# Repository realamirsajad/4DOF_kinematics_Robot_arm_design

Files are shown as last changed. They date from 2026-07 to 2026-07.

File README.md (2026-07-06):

# 4DOF_Robot Kinematics and Dynamics
4DOF arm robot for robotic and kinematics and how to design it by inventor designer cad and make a PD controller for that by Adams



The complete guideline and report can be viewed in the Instruction PDF file.

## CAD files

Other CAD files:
finalkinematic/AssemblyfinalRRPR.iam
finalkinematic/AssemblyfinalRRPR.x_t
finalkinematic/OldVersions/AssemblyfinalRRPR.0004.iam
finalkinematic/OldVersions/Part1Grroundfinal.0001.ipt
finalkinematic/OldVersions/Part1final.0001.ipt
finalkinematic/OldVersions/Part4final.0002.ipt
finalkinematic/OldVersions/Part4final.0003.ipt
finalkinematic/Part1Grroundfinal.ipt
finalkinematic/Part1final.ipt
finalkinematic/Part2final.ipt
finalkinematic/Part3final.ipt
finalkinematic/Part4final.ipt

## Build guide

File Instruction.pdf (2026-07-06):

Robot Kinematics and Dynamics report

The designed manipulator is a 4-degree-of-freedom (4-DOF) selective compliance robot intended for pick-and-place tasks on a conveyor belt. The combination of two revolute joints (RR), one prismatic joint (P), and a final revolute joint (R) allow positioning in 3D space while maintaining orientation. The prismatic joint provides vertical lift, and the offset between links ensures a larger workspace without self-collision.
According to assignment file, first we design our RRPR robot:

### 1. CAD Design (Autodesk Inventor)

- Base (orange): Fixed to ground.
- Link 1 (brown): Revolute joint (θ₁) about vertical axis.
- Link 2 (yellow): Revolute joint (θ₂) about horizontal axis.
- Link 3 (red): Prismatic joint (d₃) with an offset (non-zero distance between joint axes).
- Link 4 (light blue): End-effector, revolute joint (θ₄) about vertical axis.
Parts:
1. Ground base
As we said we have a 600 mm * 600 mm square which is fixed to the ground and it is stable and does not move. The depth of this part is 50 mm. I designed a circle as a hole in middle of this square with 100 mm diameter for connecting part 1 to that. I also added fillets for better view.

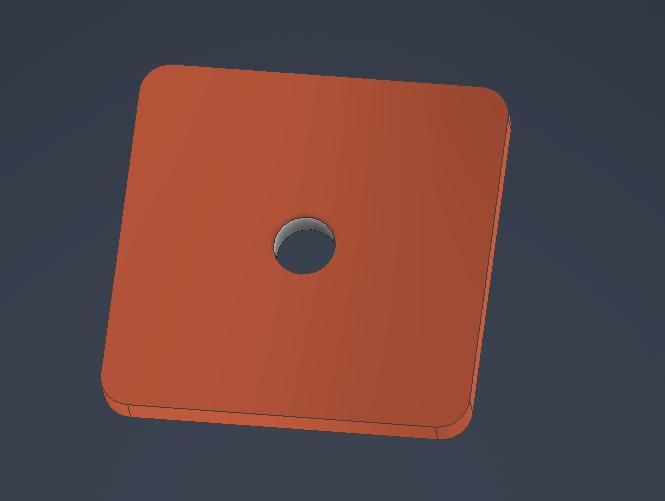
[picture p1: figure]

2. Part 1 (first revolute link)
Now we should have a cylinder attached to main part one to fit in the base part hole. So, the diameter of the hole is 100 mm again with 50 mm depth. The diameter of the base of this part is 500 mm. As it is shown in the picture below, there is a cylinder with 240 mm diameter and 750 mm height. This part 1 can rotate around itself (z axis). In the other side of this cylinder there is a empty space for moving next part freely and to circle hole with 150 mm diameter for attaching part 2. I also added fillets for better view. (l1 = 650 mm)

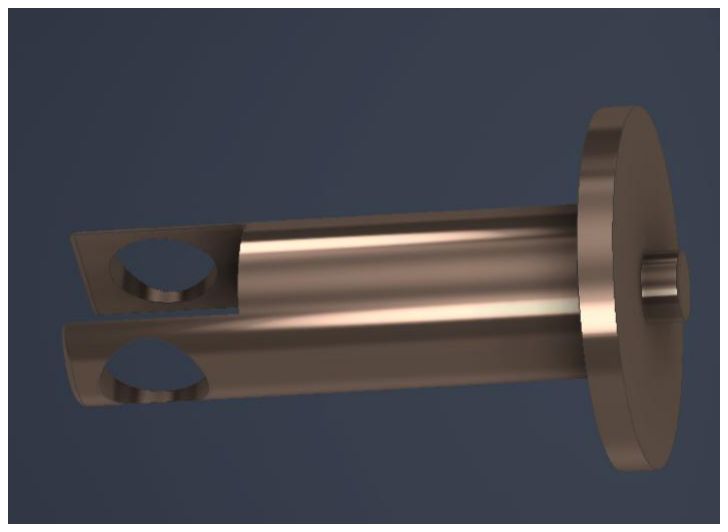
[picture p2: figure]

3. Part 2 (second revolute link)
In this part I made another horizontal cylinder for attaching to previous holes with same size (150 mm diameter again and the length of this cylinder is 240 mm). I removed a rectangular cube of this cylinder to attach the other part easier and prettier. Then I made a simple rectangular cube with 500 mm length (l2), 120 mm width, (100 mm depth). At end of this part, there is 80 mm *60 mm rectangular hole (with 2 mm fillet in each side for being more attractive), for connecting the third part. So, this part can move freely. This is another rotational part.

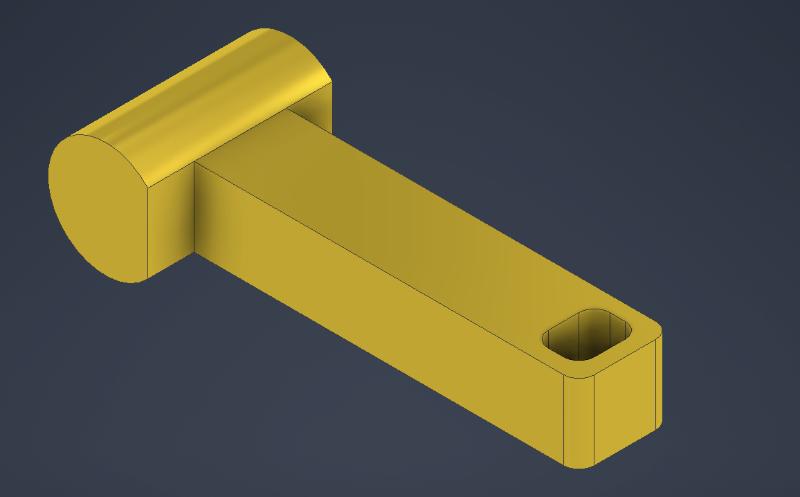
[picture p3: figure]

4. Part 3 (prismatic link)
This part is prismatic. For fitting in previous hole, the size of the rectangular cube with 500 mm length, should be 60 mm * 80 mm again. In begin of this part I designed a bigger rectangular which is 100 mm * 80 mm and 25 mm depth and the reason is this part does not pass the hole and stuck there. I also added fillets (this time around 5mm for the whole part) for better view. At other side, we have an offset (one non-zero offset between two consecutive link 4 & 5), which makes this part like a L shape, the lower part has 190 mm length (l32), and like part 1, there are 2 holes with 40 mm diameter. There are a few 2 mm fillets for better view in the last part which is not affecting the robot application.

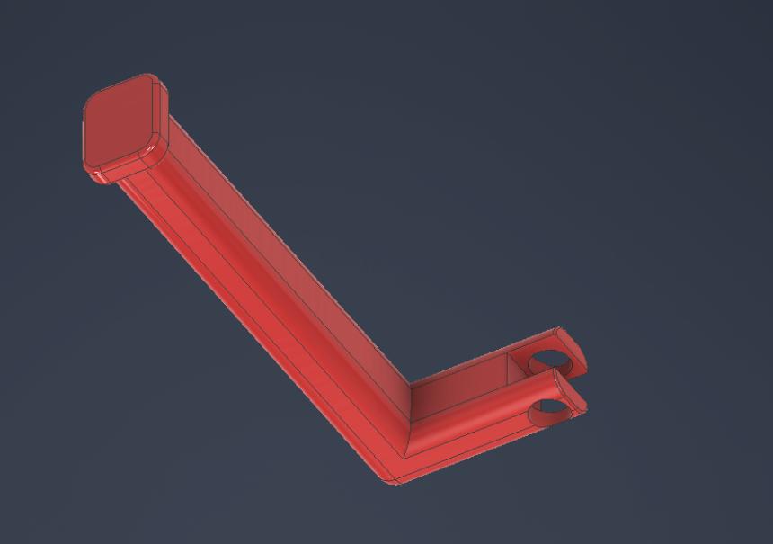
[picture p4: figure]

5. Part 4 (last revolute link)
This is a revolute part again same as part 2 we put 2 pins for locking in the previous part holes. The distance of the two holes were 80 mm. So, here the length of the two pins will be 80 mm too. There is another rectangular cube with 40 mm width, 220 mm length (l4), and 60 mm depth. End effector of this part designed pointy for being more beautiful and special functions.

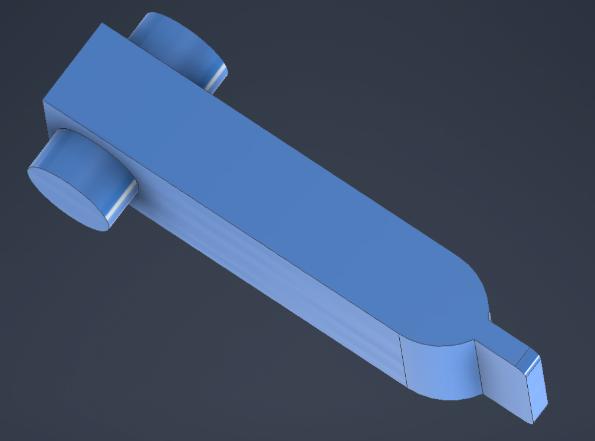
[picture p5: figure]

Assembly part
After opening inventor, we design ground part (orange) which is fixed plus 4 parts. Part 1 (brown) and part 2 (yellow) are rotational. Part 3 (red) is prismatic with an offset and part 4 (light blue) is the last part (end effector).
In this assembly part, I limited the movement of prismatic part to not separate from the robot during the movement.

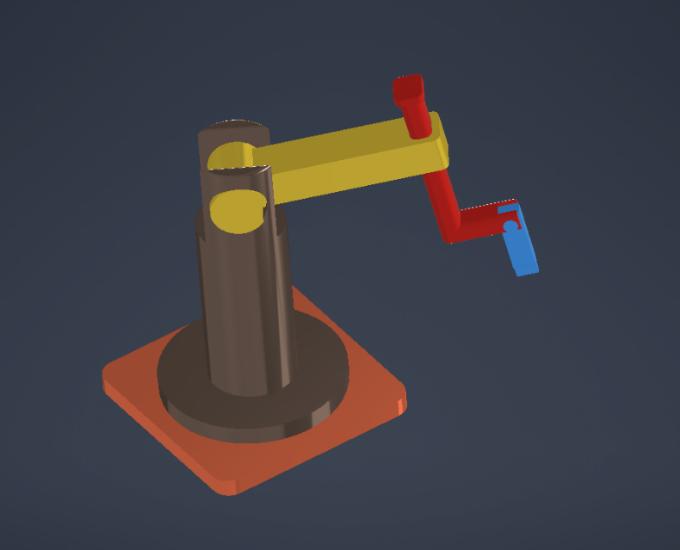
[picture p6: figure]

At the end we modify the initial position and export it for Adams PD controller design session.

### 2. Forward Kinematics

2.1 DH parameters
Find the DH parameters with the corresponding coordinate frames assigned to the base, the joints, and the end effector. Start to draw Z vectors:

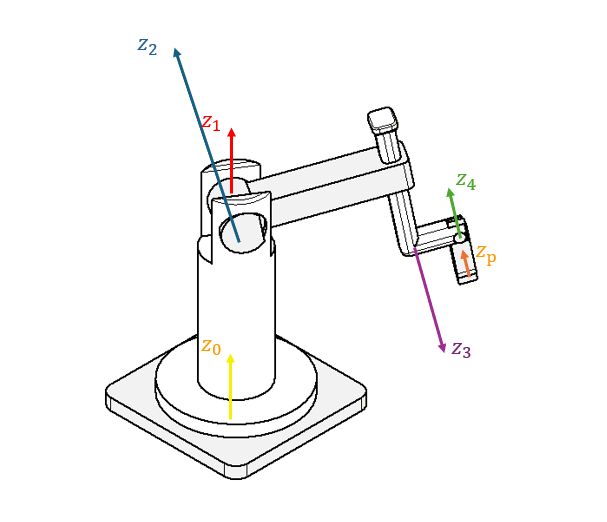
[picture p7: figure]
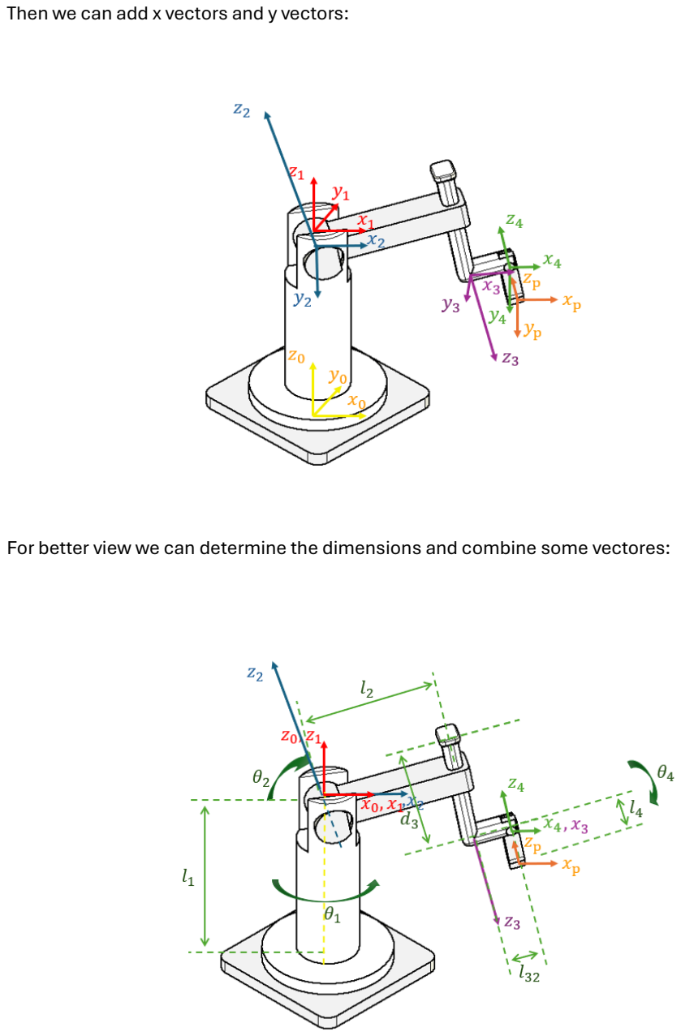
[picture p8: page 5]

Then we can add x vectors and y vectors:

For better view we can determine the dimensions and combine some vectores:

Now we can determine the DH table:

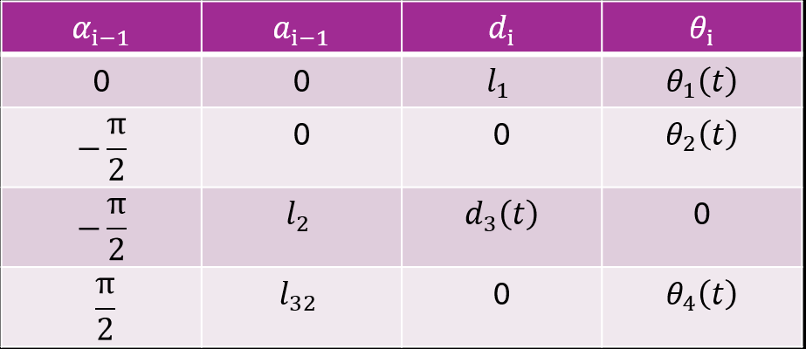
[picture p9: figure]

### 2.2 Homogeneous Transformation Matrices

Now, compute different homogeneous transformation matrices and solve the forward kinematics problems.
Each transformation matrix from frame {i-1} to {i} is:

After importing this DH table in MATLAB, next step is:
After defining DH table, now we can calculate the Homogeneous Transformation Matrices with MATLAB help for each frame (use HTM file and RRPR.mlx):

i = 1

i = 2

### DH table

i = 3

i = 4

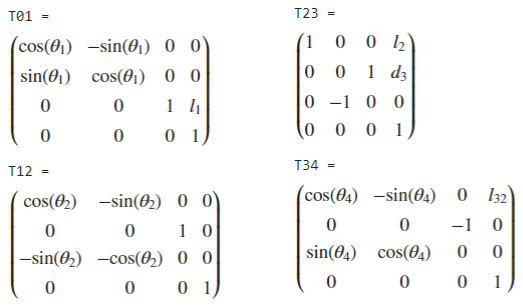
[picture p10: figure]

### 2.3 End-Effector Pose T04

T04 is achieved by multiplication of T01*T12*T23*T34 :

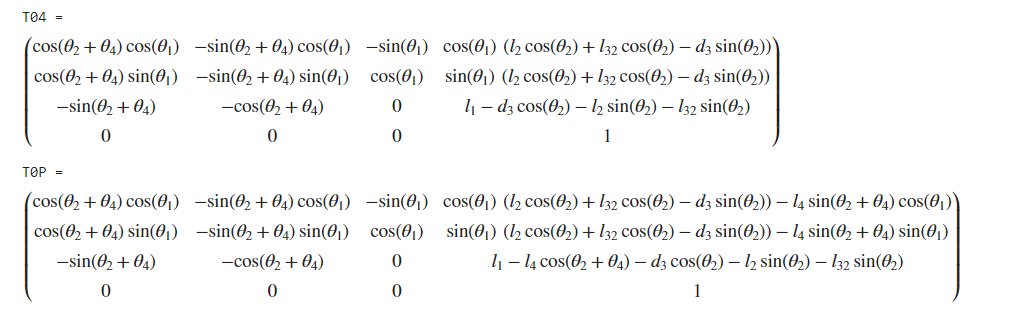
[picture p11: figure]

T0P is also can be calculated by multiplying T04 in | (because in this last
movement robot just move for +l4 in y axis).
We can test our robot by finding initial position and validating it:

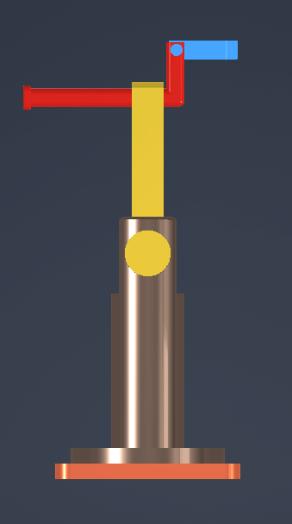
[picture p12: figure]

In z axis we have l1 (brown part) plus l2 (yellow part) plus l32 (the off set of red part) and for x axis we have l4 (light blue part) and for y axis we don’t have any vector that physically makes sense. (There is a gap before starting l4 because of limitation of movement of prismatic part but for easier calculation we consider l4 from center of base robot to end of the blue part).

### 3. Inverse kinematics:

We have another test for validation:

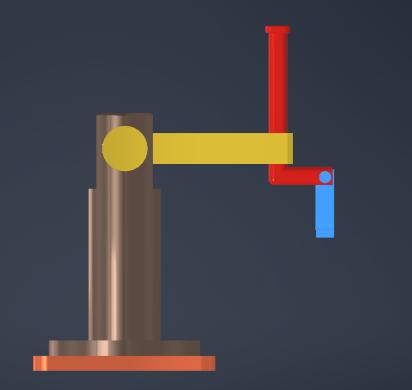
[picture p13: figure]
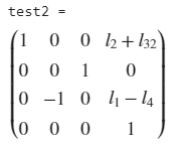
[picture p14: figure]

In this test, we have l1 (brown part) and on opposite side is l4 (blue part) in Z axis, which means l1-l4 is the transformation in this vector. (there is a gap before starting l4 because of limitation of movement of prismatic part but for easier calculation we consider l4 from center of yellow circle part to end of the blue part). In X axis also we have l2 and l32 on the same side of positive X axis which means l2+l32 is the transformation in this vector.

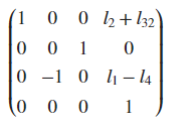
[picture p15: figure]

Note: this test is for initial position of robot too:

Forward kinematics by evaluating the end-effector pose for selected joint configurations with clear physical meaning validate and results are consistent with the expected geometry of the manipulator are verified.

For T0P calculating it by hand is like:

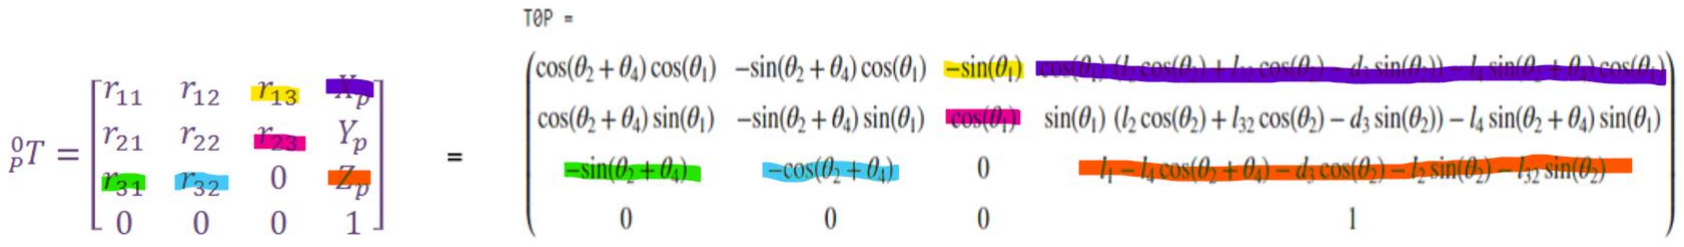
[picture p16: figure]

So according to that we can find first θ1:

r13 = −Sin (θ1)

r23 = Cos (θ1)

r31 = −Sin (θ2+θ4)

r32 = −Cos (θ2+θ4)

Yp = | ,

Yp
Sin (θ1)

= Cos (θ2

)(l2 + l32) − d3Sin (θ2) − l4Sin (θ2+θ4)

Yp
−r13

− l4r31 = Cos (θ2

)(l2 + l32)− d3Sin (θ2)

Zp =

Zp − l1 + l4Cos (θ2 + θ4

) = −d3Cos(θ2

) − (l2 + l32)Sin(θ2

)

d3Cos(θ2

) = l1 + l4r32 − Zp − (l2 + l32)Sin(θ2

) | d3 =

l1+l4r32−Zp
Cos(θ2

)

−

(l2+l32)Sin(θ2

)
Cos(θ2

)

Xp =

Xp
Cos (θ1)

= Cos (θ2

)(l2 + l32) − d3Sin (θ2) − l4Sin (θ2+θ4)

θ1 = atan2 (−r13, r23)

Xp
r23

− l4r31 = Cos (θ2

)(l2 + l32) − d3Sin (θ2)

Now we can replace d3 in this equation from Zp equation, we can calculate θ2.

We have θ2, we can calculate θ4 easily by using r31 = −Sin (θ2+θ4) equation:

Calculate the value of d3 now by replacing the θ2 in the d3 =

l1+l4r32−Zp
Cos(θ2

)

−

(l2+l32)Sin(θ2

)
Cos(θ2

)

equation:

Note: by using trigonometric relations, we could first calculate d3 and then find θ2 and θ4. Test: now for evaluating our T0P, we put θ1, θ2, θ4 = 0 and consider d3 = 0 just for easier calculations. In this case, all the cos() will be = 1 and all the sin() will be = 0. ( d3 can be any arbitrary number >0 & < 450 mm).

The result will be exactly as test 2. We can put any number for d3.

### 4. Jacobian

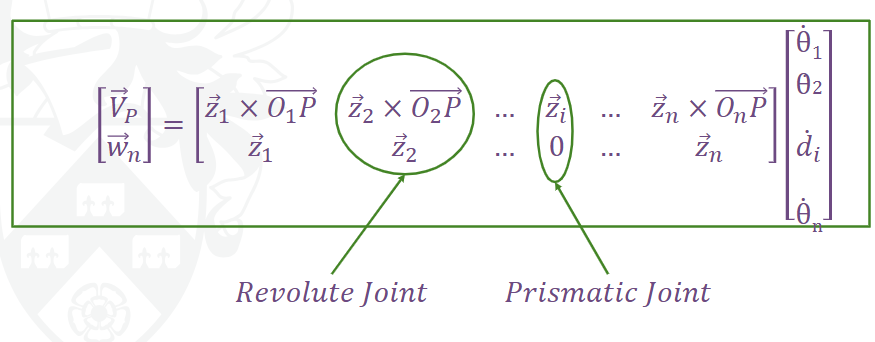
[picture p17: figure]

- Methodology & Key Steps

+d3

=

0

Since the robot has 4 degrees of freedom (RRPR), the Jacobian matrix will be a 4x6 matrix with 4 columns (each column belongs to a joint). Each Jacobian column Ji depends on whether the joint is Revolute or Prismatic:

Because the robot is a combination of revolute and prismatic joints, the best and most standard method is the Geometric Jacobian method. Extracting the Z axes of joints in the base frame. In the code, you have found the axes of motion angles by multiplying the rotation matrix by the vector [0; 0; 1]
T

So first calculate the Rotationals:

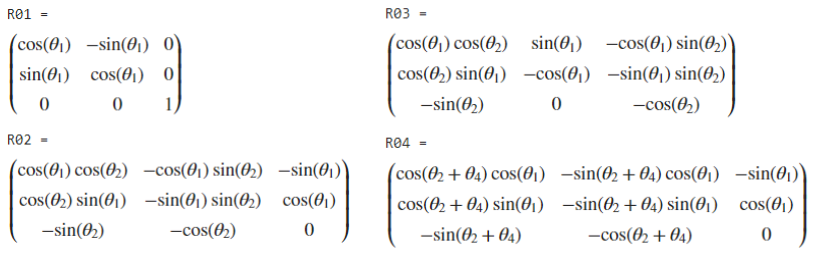
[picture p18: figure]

Now we calculate the zi
:

The end-effector in the base frame:

The distance vectors from the origin of each joint frame to the end-effector position (O0P) are computed via vector subtraction:

For O2P we have:

For O4P we have:

The Jacobian matrix has 6 rows (the first 3 rows are the linear velocity Jv and the second 3 rows are the rotational velocity (Jw) and 4 columns (the number of joints). Calculating the Jacobian using a geometric method for 4 degrees of freedom. Given that joints 1, 2, and 4 are revolute, and joint 3 is prismatic, the columns of the Jacobian matrix are formulated as follows:

First column (joint R)_1: | Second column (joint R_2):

Third column (joint P_3): | Fourth column (joint R_4):
So the main J =

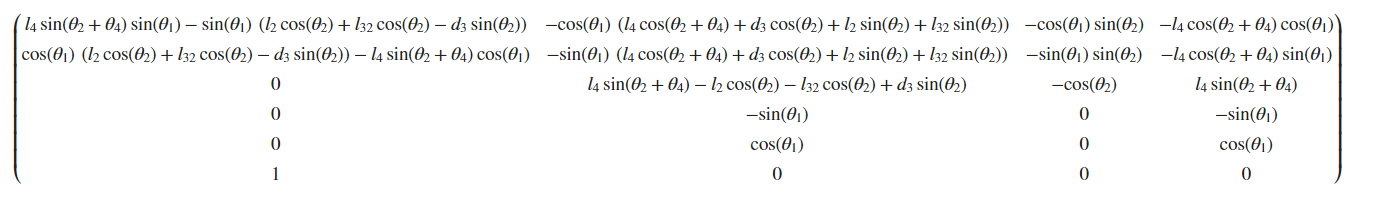
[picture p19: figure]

Potential Singular Configurations
Kinematic singularities of the 4-DOF RRPR manipulator occur when the Jacobian matrix loses its full rank (rank(J) < 4), reducing the mobility of the end-effector. According to MATLAB, the rank = 4. For this specific configuration, two main types of singularities are identified:
1. Boundary Singularity: This occurs when the manipulator reaches the outer or inner limits of its workspace (e.g., when the links are fully extended or completely folded). At these configurations, the manipulator loses the ability to move linearly along the direction of the extended links.
2. Alignment/Orientation Singularity: Since Joint 1 and Joint 4 both rotate about vertical axes under nominal conditions, a singularity occurs when the orientation of Joint 2 (θ1) aligns the axis of Joint 4 parallel to the axis of Joint 1 (z_1 parallel to z_4). In this configuration, the degrees of freedom contributed by θ̇

1 and θ̇
4 become redundant,
resulting in the loss of one independent rotational capability in the workspace.

### 4.1 Linear:

Jv =

### 4.2 Angular Velocity

The angular velocity of the last link of the robot (w) is obtained by summing the rotational velocities of each joint. Its general formula is as follows:

Since the third joint is prismatic, it does not contribute to the angular velocity of the system. The final symbolic expression is simplified using MATLAB's (simplify(J)) function to analyze singularities and workspace constraints.
and the angular velocity of the manipulator’s last link:

ω4 = Jωq̇

ω4 = θ1

̇ z1 + θ2

̇ z2 + (0)z3 + θ4

̇ z4 = θ1

̇ z1 + θ2

̇ z2 + θ4

̇ z4

### 5. Dynamics of the Manipulator (2-DOF Case)

We assume the two joints are locked at a zero joint position, resulting in a manipulator with two degrees of freedom. The robot becomes a RR (first and second revolute) after locking part 3 and 4. Derive the centrifugal and Coriolis vector, as well as the mass matrix, while considering the two joints locked. in place at a zero joint (base part) position and two joints free to move (RR).
2D case
In this part we just need first 2 parts of the whole robot:

So, in this case the new DH table and transformation matrixes are:

We can achieve T02 by multiplying T01 and T12:

The Jacobians at the COM of links are:

,

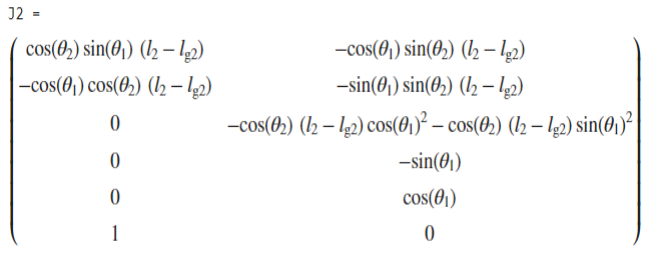
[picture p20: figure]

,
All vectors are expressed in the base frame.
So, we should calculate new OoG1, O0O1, O0G2 for 2D case:
= | - | , | = | -

O1G1=O0G1-O0O1, O1G2 =O0O1-O0G2, O2G2=O0G2-O0O2

### 5.1. Centrifugal and Coriolis Vector

As we have these equations:

Then we can express as:

CC1 =

CC2 =

### 5.2. Mass Matrix

The extracted inertial properties of active manipulator from Autodesk Inventor using physical properties tool (I1 as a steel carbon and I2 as a steel material):

Lg1 = l1 – X = 650 mm – 234.306 mm = 415.694 mm, Mass 1 = 269.864 kg Lg2 = l2 – X = 500 mm - 168.176 mm = 331.824 mm, Mass 2 = 75.015 kg

M =

### 5.3 Total Potential Energy

Under the assumption that two joints are locked in place and the manipulator has two degrees of freedom. Sum of the potential energies of the two mobile links is V and , the potential energy is:

V = V1 + V2
Where:
- V1: Potential Energy of link 1.
- V2: Potential Energy of link 2.

### 5.4 Gravity Vector

Gravity Vector (the torque vector due to gravity terms in the equation of motion), considering that only the two joints are free to move.

Our Gravity Vector can be expressed as:

Equations of motion:

In the presence of no external forces, the general form of the equations of motion is:

We define a geometric/mass constant term as follows:

So τ=

### 6. Control in Joint Space (PD Controller)

We are using ADAMS-View (two joints are free to move):
1. After exporting our assembly in the Inventor file, and importing it to ADAMS-View,
2. In order to accurately calculate physical properties and inertia, the material of all parts is set to “steel”.
3. Now we define the markers in right place and axis and use connectors part based on the vectors. We use fix connector fore base, and revolute for part 1,2 and 4 and prismatic for part 3.
4. Lock two joints so that the manipulator has two degrees of freedom.
5. Now start designing PD.:
For joint 1 we have in this case, ADAMS assigns MARKER_14 and MARKER_15, and for joint 2 we have ADAMS assigns MARKER_20 and MARKER_21.
For revolute joints we have:

After configuring the model to accept joint torques and return the computed joint positions and velocities:
Error_Angular_Position_Joint_2 = Desired_Theta_2 - Theta_2 Error_Angular_Position_Joint_1 = Desired_Theta_1 - Theta_1 Error_Angular_Velocity_Joint_2 = Desired_Theta_2P - Theta_2P Error_Angular_Velocity_Joint_1 = Desired_Theta_1P - Theta_1P

SFORCE_3 for first link:
SFORCE_3 = Kp*Error_Angular_Position_Joint_1 + Kv* Error_Angular_Velocity_Joint_1

SFORCE_2 for second link:
SFORCE_2 = Kp_2*Error_Angular_Position_Joint_2 + Kv_2* Error_Angular_Velocity_Joint_2

Evaluate controller performance for step input:
We defied theta_1, theta_2, as our measurement Desired_Theta_1 = pi/4 and Desired_Theta_2 = - pi/4 are our input. theta_1P, theta_2P measured angular velocity. Desired_Theta_1P = 0, Desired_Theta_2P = 0 because they are the derivative of step function, which is zero.

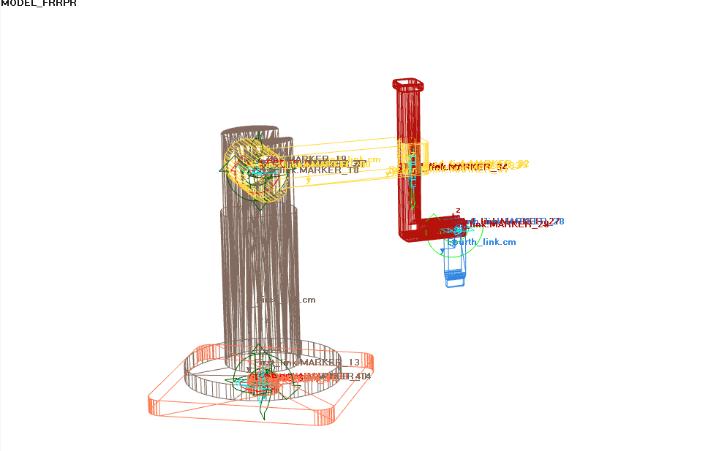
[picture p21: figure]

PD controller with joint position and velocity feedback:
The controller receives joint position and velocity information from the robot model and sends torque commands to drive the robot to a desired joint position.

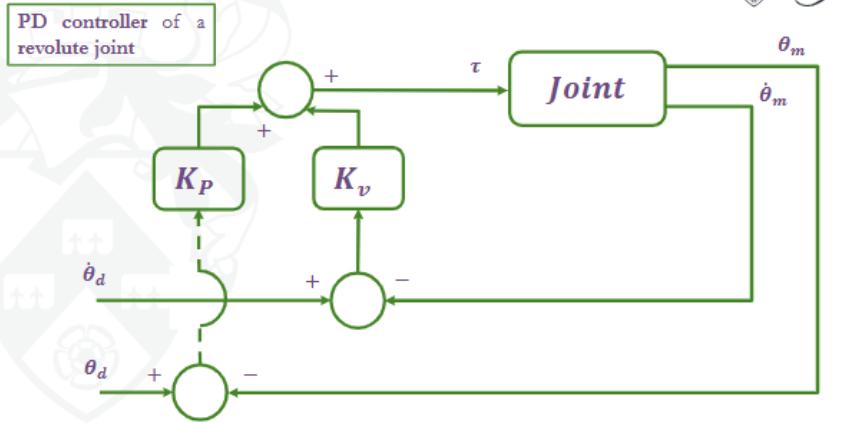
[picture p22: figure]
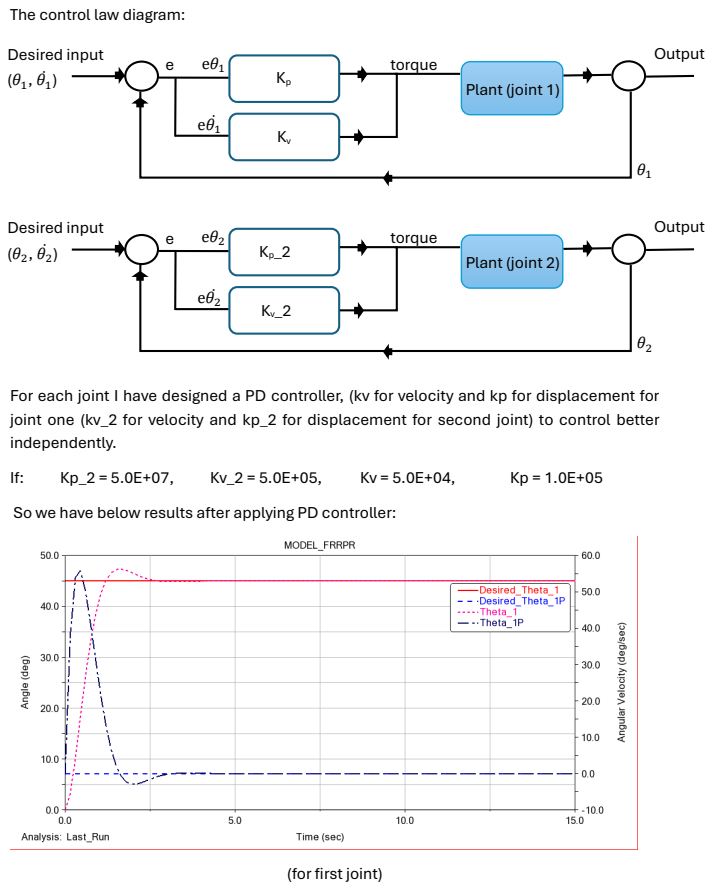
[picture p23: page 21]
Desired input; torque; Plant (joint 1); Output; Plant (joint 2)

The control law diagram:

For each joint I have designed a PD controller, (kv for velocity and kp for displacement for
joint one (kv_2 for velocity and kp_2 for displacement for second joint) to control better
independently.
So we have below results after applying PD controller:

(for first joint)

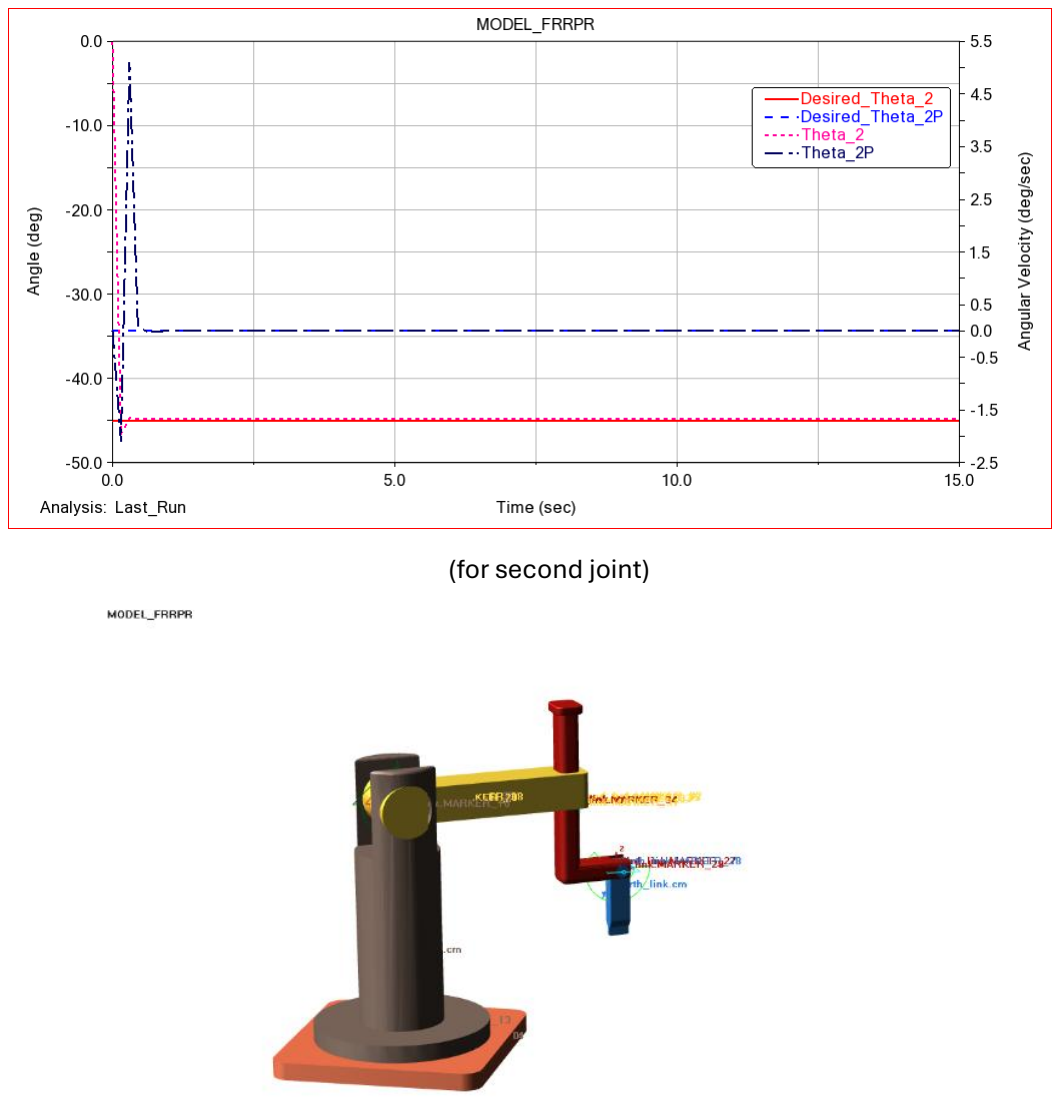
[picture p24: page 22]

(for second joint)
